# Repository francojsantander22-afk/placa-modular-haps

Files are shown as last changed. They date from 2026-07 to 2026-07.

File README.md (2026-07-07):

# main_board_habp

Placa principal (main board) del sistema de adquisición de datos y telemetría para un **globo meteorológico de alta altitud (HABP – High Altitude Balloon Project)**, diseñada en KiCad. Este repositorio contiene el esquemático, el PCB y los archivos de proyecto de la placa que integra el microcontrolador, la red de sensores, el módulo GPS, el enlace LoRa y el sistema de gestión de energía del nodo.

Este proyecto forma parte de una pasantía en CEGA Electrónica, desarrollada por **Franco Santander** y **Lisandro Elmelaj**.

## Descripción general

El objetivo del sistema es recolectar variables físicas del entorno y datos de posicionamiento durante el vuelo de un globo de alta altitud, empaquetarlos de forma eficiente y transmitirlos por radiofrecuencia mediante LoRa, todo en un nodo autónomo capaz de operar en condiciones extremas (hasta ~30 km de altitud, presión menor a 1 kPa y temperaturas de hasta -70 °C).

El sistema completo se organiza en cuatro subsistemas funcionales:

1. Red de sensores
2. Procesamiento de datos y empaquetado
3. Gestión de energía
4. Enlace de comunicaciones (LoRa)

## Hardware

### Microcontrolador

El núcleo del sistema es un microcontrolador de la familia **STM32** (STM32WL55C), montado sobre el módulo **Quectel KG200Z**, que integra de fábrica la etapa de radiofrecuencia LoRa.

### Red de sensores (bus I2C)

Todos los sensores se comunican por I2C (interfaz `I2C3`):

- **BMI270** – IMU de 6 grados de libertad (acelerómetro + giroscopio) con sensor de temperatura interno.
- **SHT21** – Temperatura y humedad ambiente.
- **MS5611** – Presión atmosférica absoluta y temperatura (cálculo de altitud redundante).
- **CMPS2** – Magnetómetro, orientación y azimut respecto al norte magnético.

### Posicionamiento y depuración (UART)

- **ATGM336H (GPS)** vía `USART1`, con recepción por interrupciones sobre un ring buffer de 512 bytes y parsing de tramas NMEA (`GGA`, `VTG`).
- **Consola de telemetría** vía `USART2`, usada como puerto de depuración.

### Gestión de energía

- Celda de litio **18650 en configuración 1S** (3.0 V–4.2 V).
- **BMS** basado en DW01A + FS8205A (protección de sobretensión, subtensión y sobrecorriente).
- Cargador solar **BQ24074** (Texas Instruments), con gestión dinámica de potencia (DPM) entre panel solar y batería.
- Medición de batería por ADC (`PB1`) con divisor resistivo, sobremuestreo y filtro EMA para estimar el estado de carga (SoC).
- Sistema de calefacción para mantener la celda por encima de 0 °C (corte de encendido/apagado en 10 °C / 22 °C).

## Protocolo de comunicaciones: empaquetado TLVPara minimizar el tiempo en el aire (*time-on-air*) del enlace LoRa, el firmware arma un payload binario bajo el esquema **TLV (Type-Length-Value)** en lugar de texto plano, incluyendo únicamente las variables válidas en cada transmisión (por ejemplo, se omiten las coordenadas si el GPS todavía no tiene *fix*).

| Tag | Descripción | Longitud | Formato |
|-----|---|---|---|
| `0x01` | Hora UTC (GPS) | 3 bytes | Horas, minutos, segundos |
| `0x02` | Coordenadas GPS | 8 bytes | Latitud y longitud (`int32_t`) |
| `0x03` | Altitud GPS | 2 bytes | Metros sobre el nivel del mar |
| `0x04` | Velocidad de desplazamiento | 2 bytes | km/h (×100) |
| `0x05` | Aceleración (IMU) | 6 bytes | Ejes X, Y, Z (`int16_t`) |
| `0x06` | Giroscopio (IMU) | 6 bytes | Ejes X, Y, Z (`int16_t`) |
| `0x07` | Temperatura SHT21 | 2 bytes | °C (×100) |
| `0x08` | Humedad SHT21 | 2 bytes | % (×100) |
| `0x09` | Presión atmosférica (MS5611) | 4 bytes | mbar (×100, `uint32_t`) |
| `0x0B` | Voltaje de batería | 2 bytes | mV (`uint16_t`) |
| `0x0C` | Estado de carga (SoC) | 1 byte | % (0–100) |
| `0x0D` | Azimut (magnetómetro) | 2 bytes | Grados (×100) |
| `0x0E` | Temperatura de batería (DS18B20) | 2 bytes | °C (×100) |
| `0x0F` | Estado del calefactor | 1 byte | Booleano (1 = ON, 0 = OFF) |

El enlace opera en la banda ISM de 915 MHz (configurable a 917.3 MHz), con BW = 125 kHz y SF7 por defecto, gestionado mediante una máquina de estados no bloqueante sobre el secuenciador `UTIL_SEQ`, con ventana de escucha de ACK de 3000 ms tras cada transmisión.

## Diseño de PCB

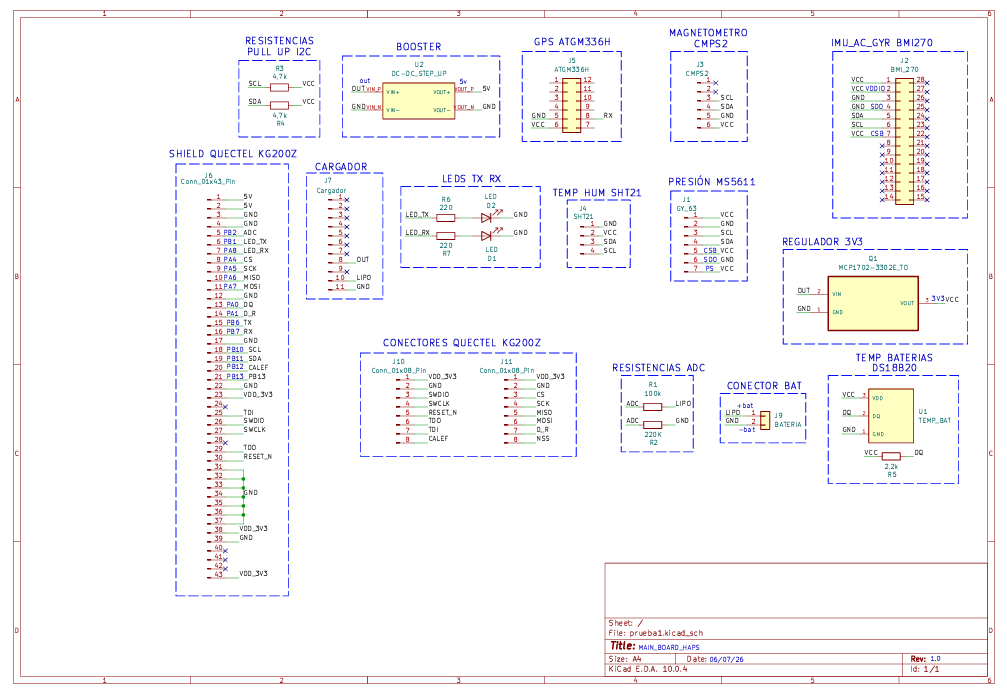
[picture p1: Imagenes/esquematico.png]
Esquemático completo

*Esquemático completo del nodo sensor, capturado de forma jerárquica en KiCad.*

El diseño se realizó en **KiCad**, de forma modular (para poder acoplar directamente los sensores utilizados durante el desarrollo, dejando la versión SMD final para la etapa posterior de integración).

- **2 capas**: capa superior para ruteo de señales y componentes, capa inferior con plano de masa (GND) continuo, plano de alimentación (VCC) y bus I2C.
- Distribución de componentes pensada para minimizar interferencia electromagnética (EMI): el módulo de energía (MPPT) y los conectores de batería en un extremo, el transceptor LoRa/GPS alejado de fuentes de ruido de conmutación.
- Copper pour de GND en las capas exteriores y pistas anchas en la zona del conversor DC-DC (BQ25570) para soportar picos de corriente.
- Orificios de montaje (*mounting holes*) para fijación mecánica al chasis de la sonda.

| Top Layer | Bottom Layer | Top + Bottom |
|:---:|:---:|:---:|
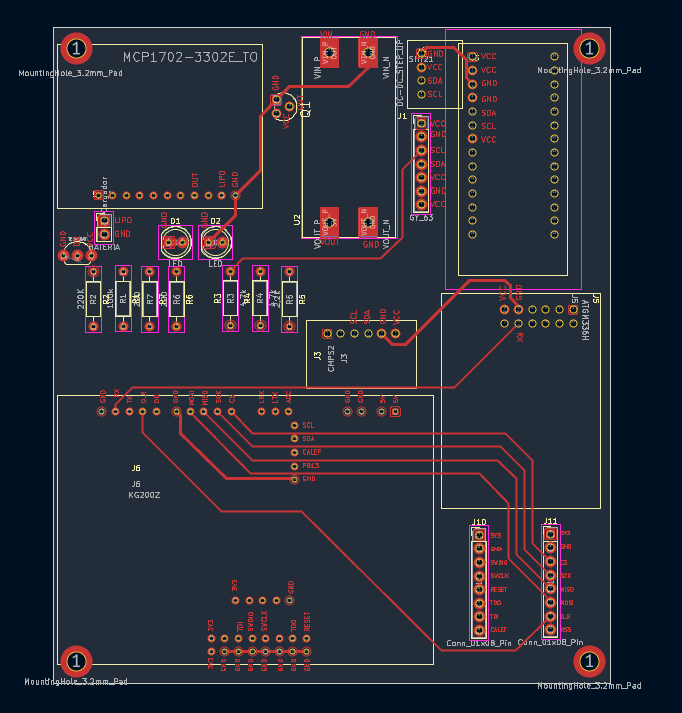
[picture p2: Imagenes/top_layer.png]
Top Layer
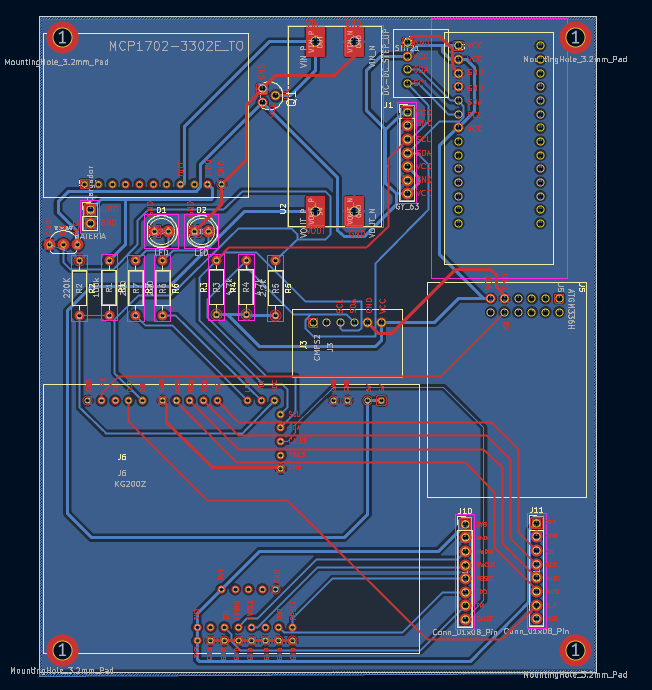
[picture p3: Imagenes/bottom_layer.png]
Bottom Layer
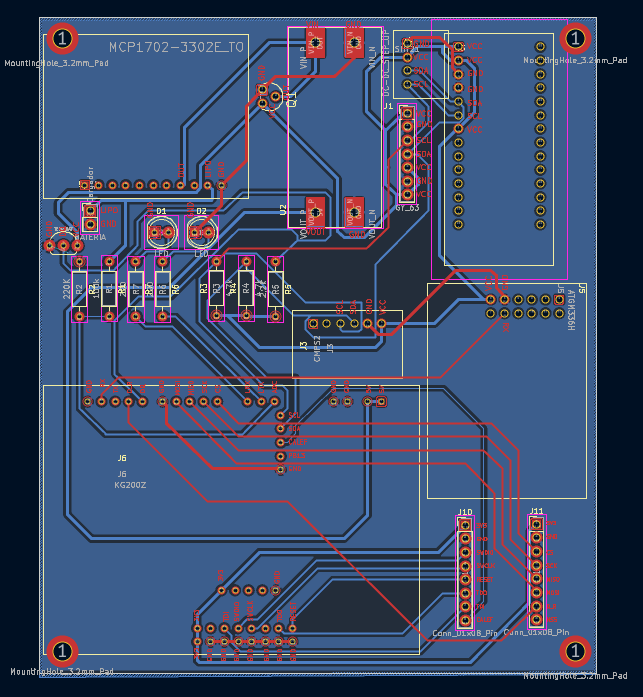
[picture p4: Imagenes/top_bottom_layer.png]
Top Bottom Layer
|  |  |  |

### Modelado 3D

| Vista frontal | Vista trasera |
|:---:|:---:|
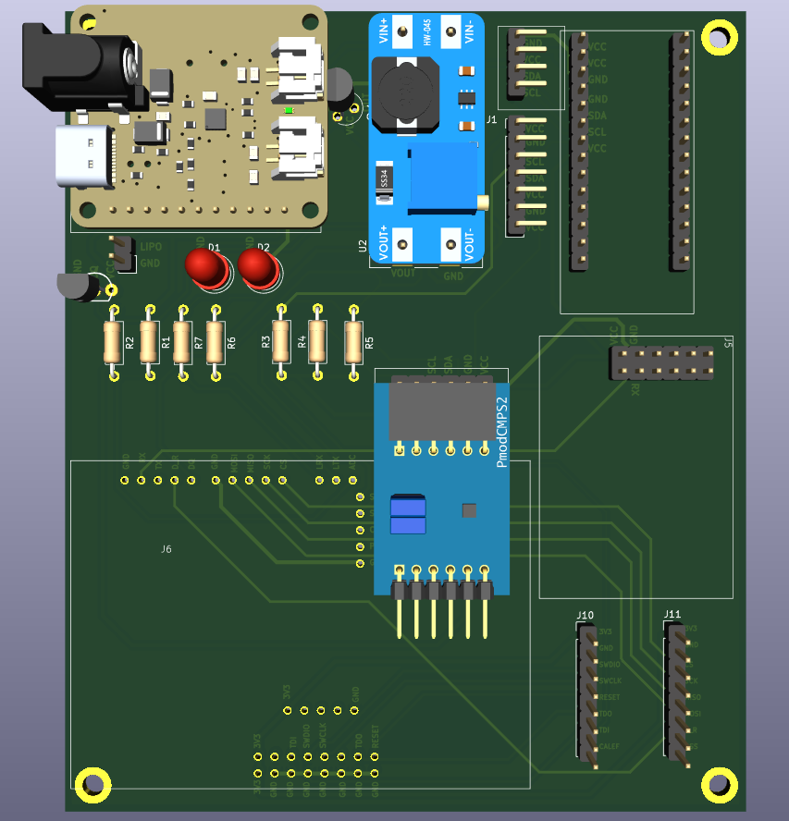
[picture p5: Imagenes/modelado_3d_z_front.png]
Modelado 3D vista frontal
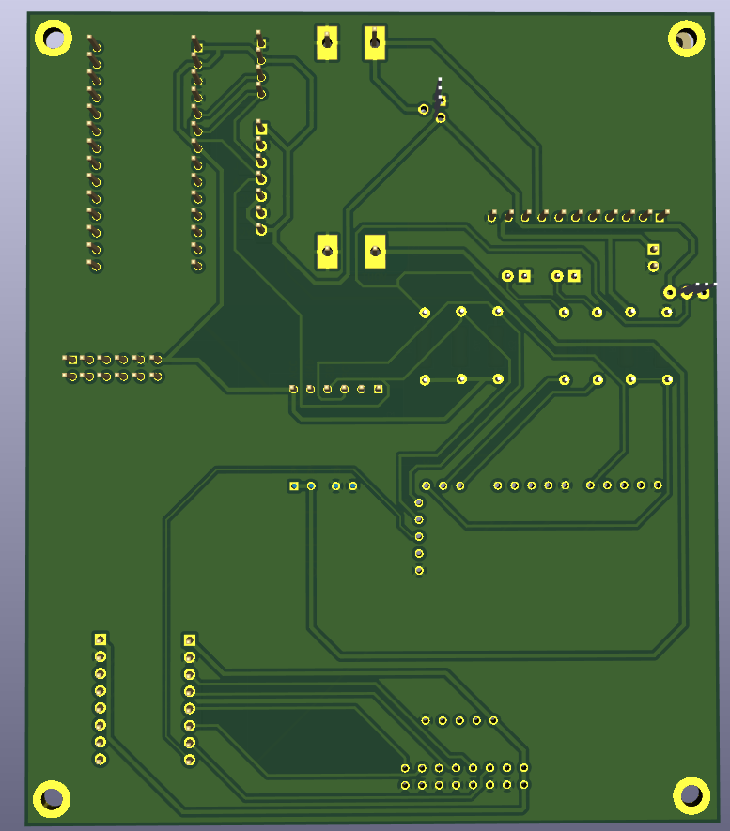
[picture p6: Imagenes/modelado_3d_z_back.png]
Modelado 3D vista trasera
|  |  |

### Archivos del repositorio

- `prueba1.kicad_pro` / `prueba1.kicad_sch` / `prueba1.kicad_pcb` — proyecto, esquemático y PCB de KiCad.
- `prueba1.kicad_prl` — configuración de proyecto.
- `esquemático.pdf` — esquemático completo exportado.
- `fp-lib-table` / `sym-lib-table` — tablas de librerías de footprints y símbolos.
- `madeinhome.pretty/` — librería de footprints propia.
- `Imagenes/` — renders y capturas del esquemático, capas y modelado 3D de la placa.

## Repositorios relacionados

Este repositorio contiene únicamente el diseño de hardware (PCB). El firmware del proyecto está dividido en repositorios separados:

- **[shield_board_kg200z](https://github.com/francojsantander22-afk/shield_board_kg200z)** — Placa/shield de acople para el módulo Quectel KG200Z.
- **[sensores](https://github.com/francojsantander22-afk/sensores)** — Drivers e integración de la red de sensores (BMI270, SHT21, MS5611, CMPS2).
- **[lora_tx_sensores](https://github.com/francojsantander22-afk/lora_tx_sensores)** — Firmware del nodo transmisor: adquisición de sensores, empaquetado TLV y envío por LoRa.
- **[lora_rx_deco](https://github.com/francojsantander22-afk/lora_rx_deco)** — Firmware del receptor en tierra: recepción del enlace LoRa y decodificación del protocolo TLV.

## Autores

- Franco Santander
- Lisandro Elmelaj

Proyecto desarrollado en el marco de una pasantía en **CEGA Electrónica**.

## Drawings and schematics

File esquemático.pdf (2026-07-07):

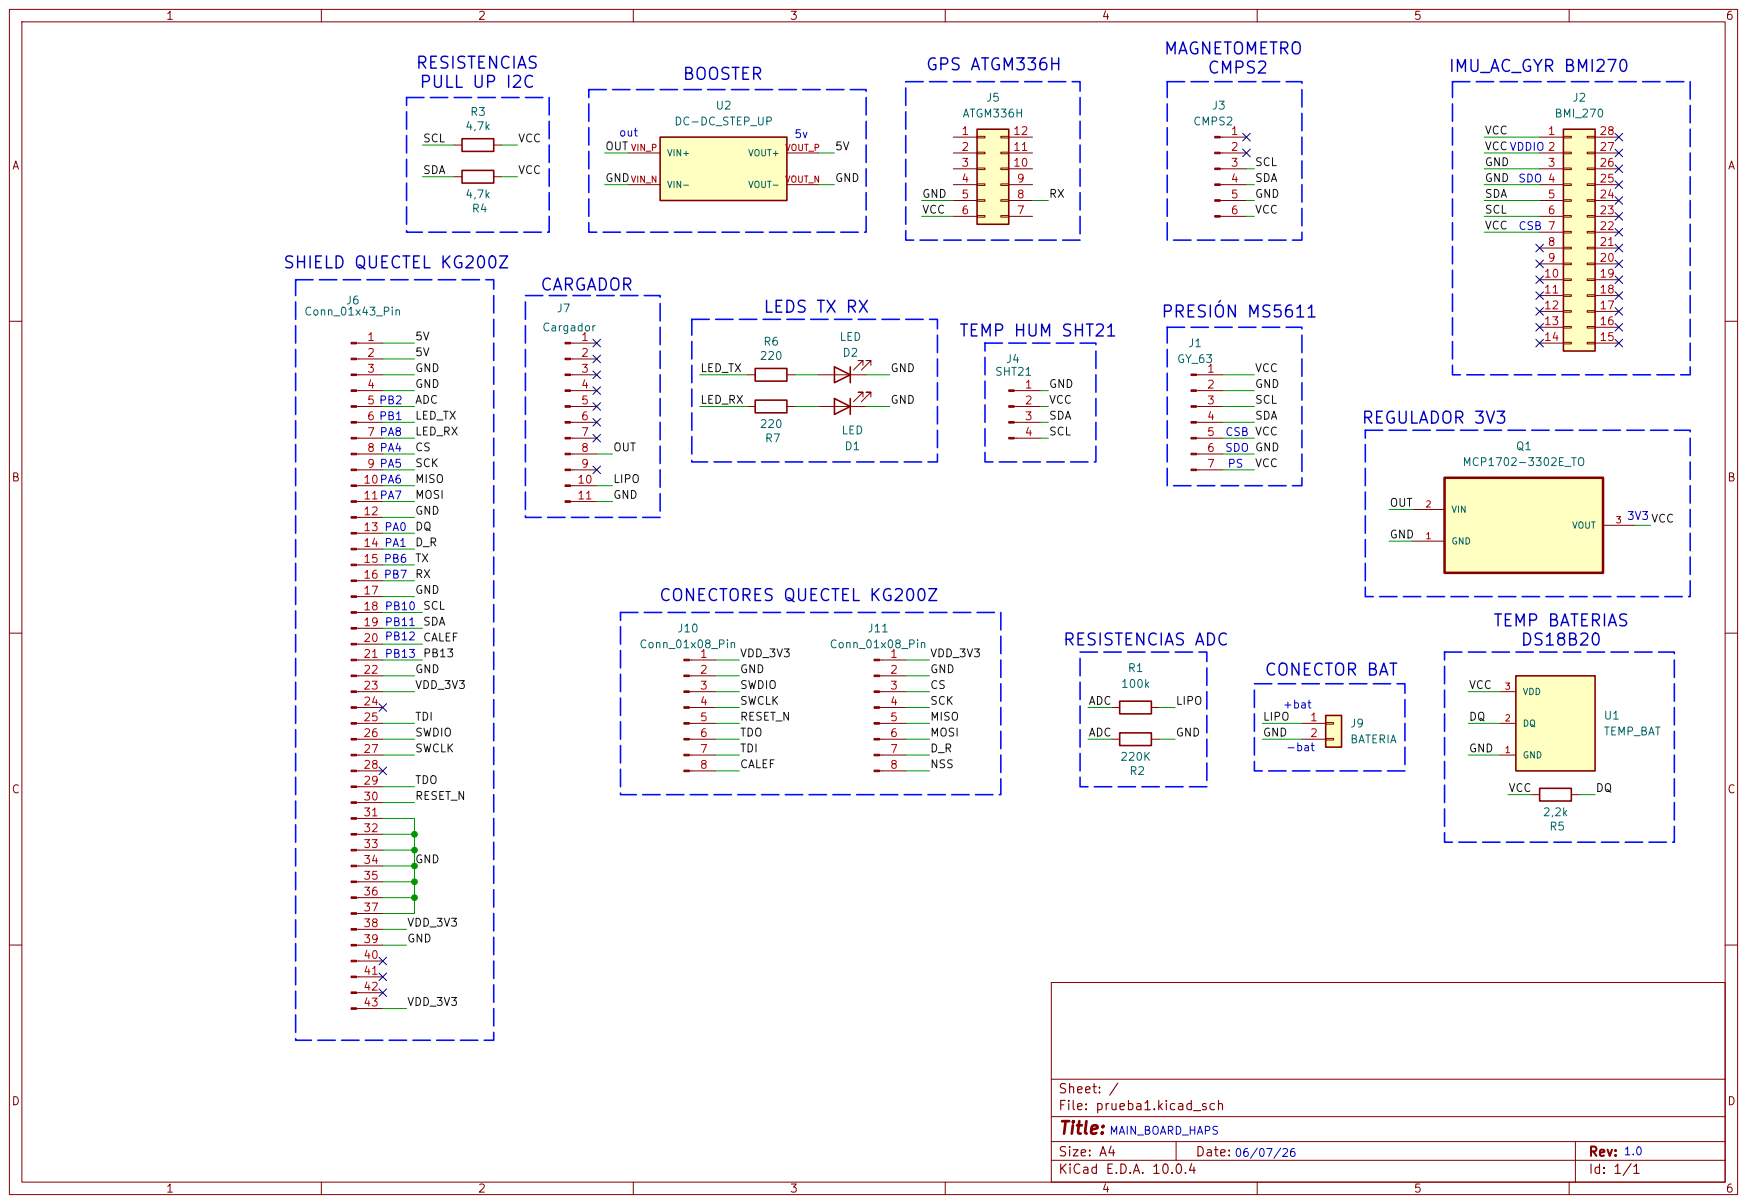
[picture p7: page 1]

-bat LEDS TX RX

Size: A4 | 06/07/26 | Rev: 1.0
KiCad E.D.A. 10.0.4 | | Id: 1/1

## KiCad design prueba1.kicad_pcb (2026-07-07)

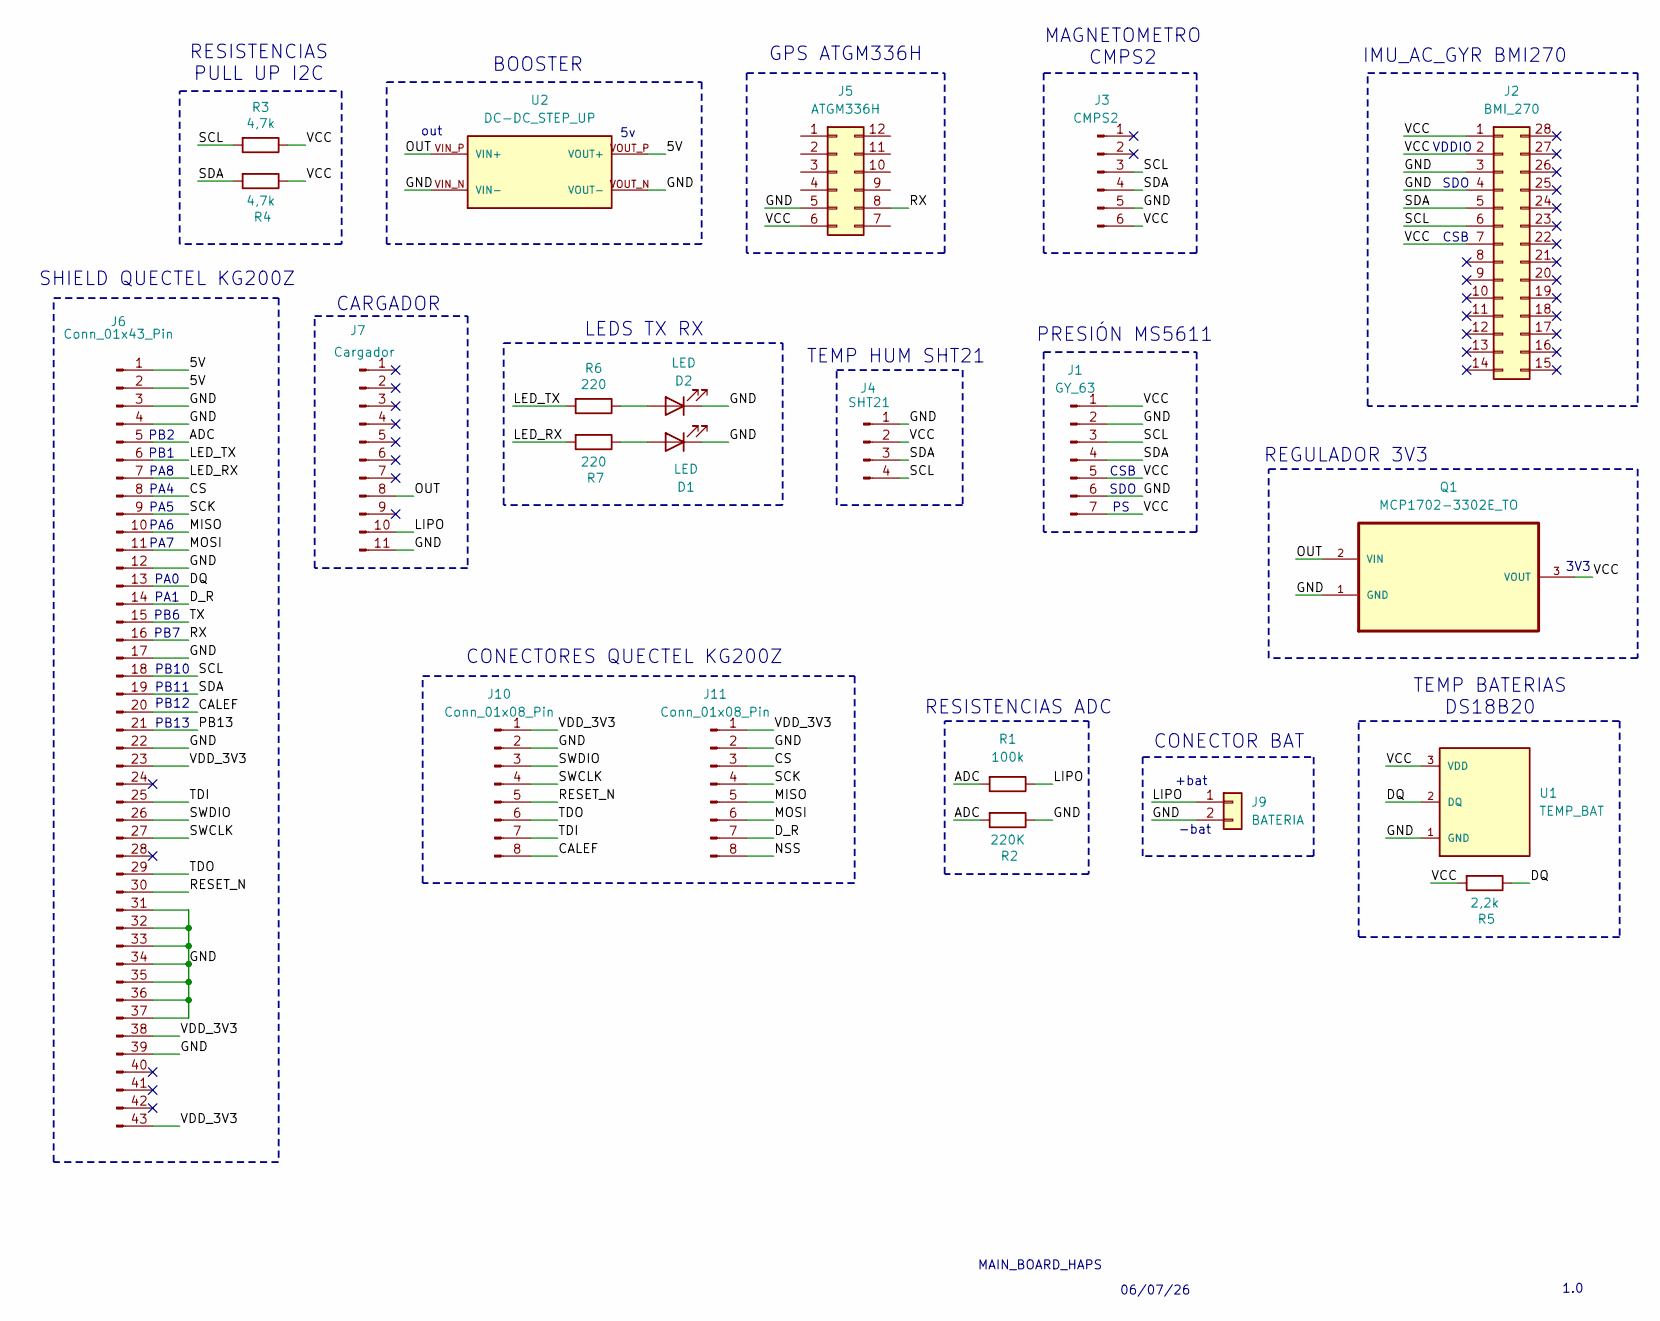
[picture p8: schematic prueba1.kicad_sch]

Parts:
D1, D2: LED; LED_D5.0mm
J1: GY_63; PinHeader_1x07_P2.54mm_Vertical
J2: BMI_270
J3: CMPS2
J4: SHT21
J5: ATGM336H
J6: Conn_01x43_Pin; socket_cont
J7: Cargador; cargador
J9: BATERIA; PinHeader_1x02_P2.54mm_Vertical
J10, J11: Conn_01x08_Pin; PinHeader_1x08_P2.54mm_Vertical
Q1: MCP1702-3302E_TO; TO127P254X533-3; MPN MCP1702-3302E/TO
R1: 100k; R_Axial_DIN0207_L6.3mm_D2.5mm_P10.16mm_Horizontal
R2: 220K; R_Axial_DIN0207_L6.3mm_D2.5mm_P10.16mm_Horizontal
R3, R4: 4,7k; R_Axial_DIN0207_L6.3mm_D2.5mm_P10.16mm_Horizontal
R5: 2,2k; R_Axial_DIN0207_L6.3mm_D2.5mm_P10.16mm_Horizontal
R6, R7: 220; R_Axial_DIN0207_L6.3mm_D2.5mm_P10.16mm_Horizontal
U1: TEMP_BAT; TO-92-AMMO
U2: DC-DC_STEP_UP; MODULE_MT3608_DC-DC_STEP_UP_CONVERTER_2A_BOOSTER_MODULE

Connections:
/5V: J6.1, J6.2, U2.VOUT_P (VOUT+)
/ADC: J6.5, R1.2, R2.2
/CALEF: J6.20, J10.8
/CS: J6.8, J11.3
/DQ: J6.13, R5.1, U1.2 (DQ)
/D_R: J6.14, J11.7
/GND: D1.1 (K), D2.1 (K), J1.2, J1.6, J2.3, J2.4, J3.5, J4.1, J5.5, J6.3, J6.4, J6.12, J6.17, J6.22, J6.31, J6.32, J6.33, J6.34, J6.35, J6.36, J6.37, J6.39, J7.11, J9.2, J10.2, J11.2, Q1.1 (GND), R2.1, U1.1 (GND), U2.VIN_N (VIN-), U2.VOUT_N (VOUT-)
/LED_RX: J6.7, R7.2
/LED_TX: J6.6, R6.2
/LIPO: J7.10, J9.1, R1.1
/MISO: J6.10, J11.5
/MOSI: J6.11, J11.6
/NSS: J11.8
/OUT: J7.8, Q1.2 (VIN), U2.VIN_P (VIN+)
/PB13: J6.21
/RESET_N: J6.30, J10.5
/RX: J5.8, J6.16
/SCK: J6.9, J11.4
/SCL: J1.3, J2.6, J3.3, J4.4, J6.18, R3.2
/SDA: J1.4, J2.5, J3.4, J4.3, J6.19, R4.2
/SWCLK: J6.27, J10.4
/SWDIO: J6.26, J10.3
/TDI: J6.25, J10.7
/TDO: J6.29, J10.6
/TX: J6.15
/VCC: J1.1, J1.5, J1.7, J2.1, J2.2, J2.7, J3.6, J4.2, J5.6, Q1.3 (VOUT), R3.1, R4.1, R5.2, U1.3 (VDD)
/VDD_3V3: J6.23, J6.38, J6.43, J10.1, J11.1
unnamed: D1.2 (A), R7.1
unnamed: D2.2 (A), R6.1

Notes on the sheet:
CSB
PA7
REGULADOR 3V3
MAGNETOMETRO CMPS2
+bat
PA1
SHIELD QUECTEL KG200Z
MAIN_BOARD_HAPS
SDO
LEDS TX RX
out
PA8
PA5
PB7
06/07/26
TEMP HUM SHT21
PA0
PB1
CARGADOR
PB10
PB13
RESISTENCIAS PULL UP I2C
PA4
VDDIO
RESISTENCIAS ADC
1.0
PB12
CONECTORES QUECTEL KG200Z
PB6
BOOSTER
IMU_AC_GYR BMI270
GPS ATGM336H
TEMP BATERIAS DS18B20
CONECTOR BAT
3V3
PB11
PB2
PA6
-bat
PRESIÓN MS5611

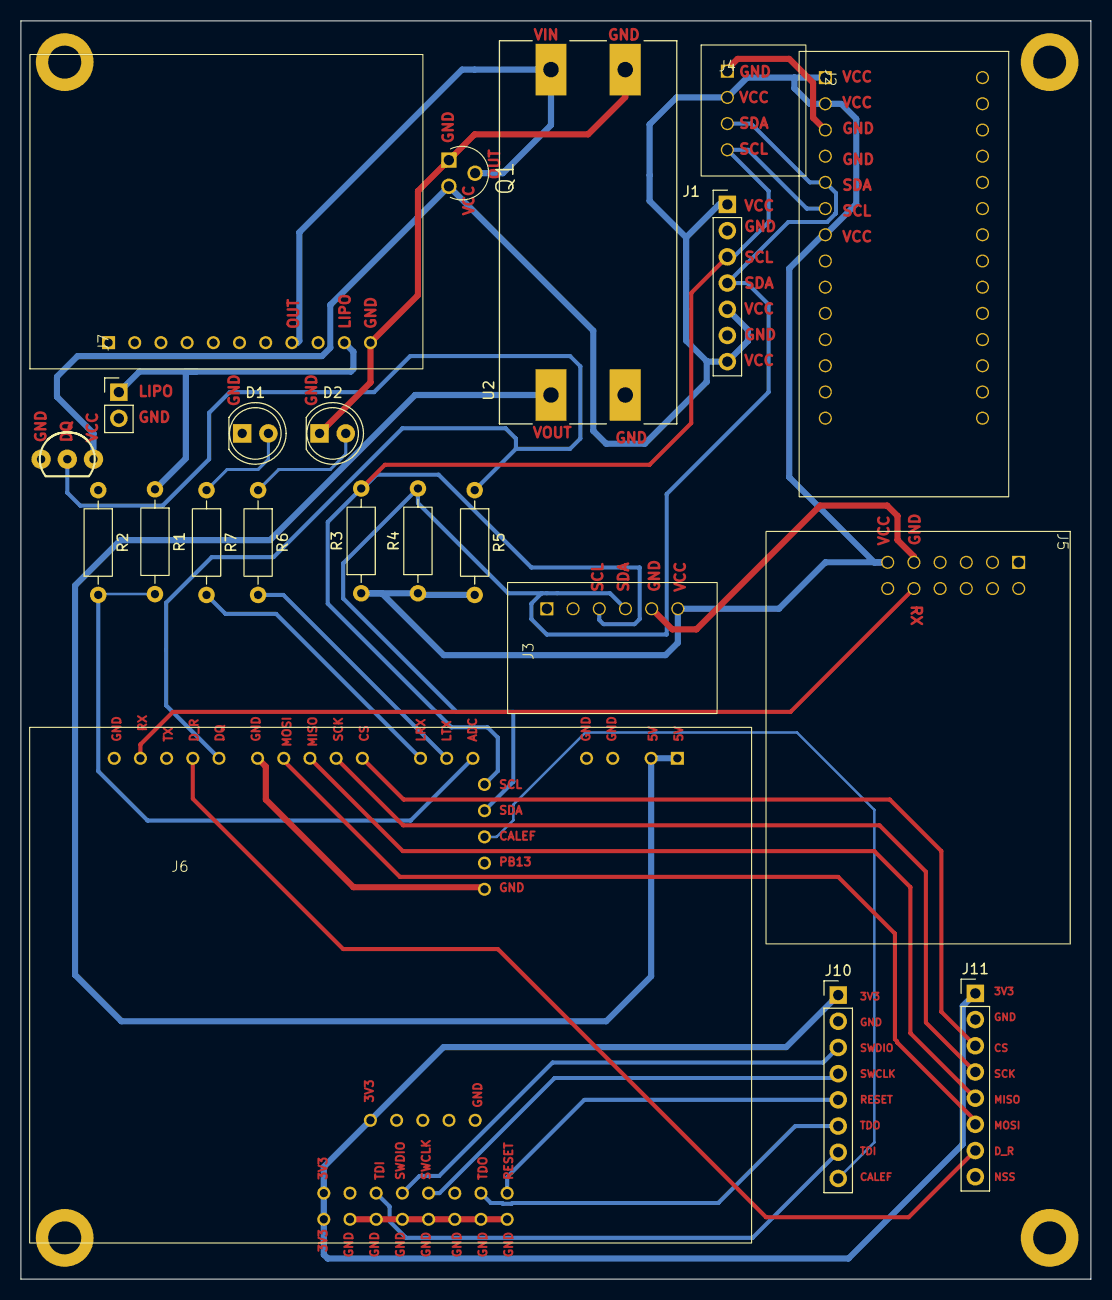
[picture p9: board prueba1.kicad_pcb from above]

Board: 2 copper layers, 103.8 x 122.0 mm, 22 parts (0 on the bottom side), 26 nets.

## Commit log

2026-06-26 Esquematico inicial, footprints y modelos 3d
    [prueba1.kicad_pcb, prueba1.kicad_sch]
2026-07-01 Nuevos cambios
    [prueba1.kicad_pcb, prueba1.kicad_sch]
2026-07-07 pcb terminada
    [prueba1.kicad_pcb, prueba1.kicad_sch]
